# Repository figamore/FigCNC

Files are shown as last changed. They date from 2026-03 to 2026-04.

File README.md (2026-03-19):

# FigCNC

**FigCNC** is an open-source CNC controller board based on the ESP32 microcontroller, designed to run [FluidNC](https://github.com/bdring/FluidNC) firmware. It provides a compact and clean interface between the ESP32 and external stepper motor drivers, with optocoupler-isolated limit switch inputs, a tool-length probe input, onboard microSD storage for G-code files, and a pendant UART interface — all powered directly from the machine's 12–36 V supply rail.

FigCNC includes an RS485 interface (MAX3485 transceiver) for direct Modbus RTU control of Huanyang-compatible VFD spindles, making it suitable for machines that require closed-loop spindle speed management.

## Table of Contents

- [Features](#features)
- [Board Overview](#board-overview)
- [Electrical Specifications](#electrical-specifications)
- [PCB Layout](#pcb-layout)
- [Manufacturing](#manufacturing)
- [GPIO Pin Reference](#gpio-pin-reference)
- [Connectors](#connectors)
- [FluidNC Configuration](#fluidnc-configuration)
- [Provided Configuration Files](#provided-configuration-files)
- [Pendant](#pendant)
- [License](#license)

<br>

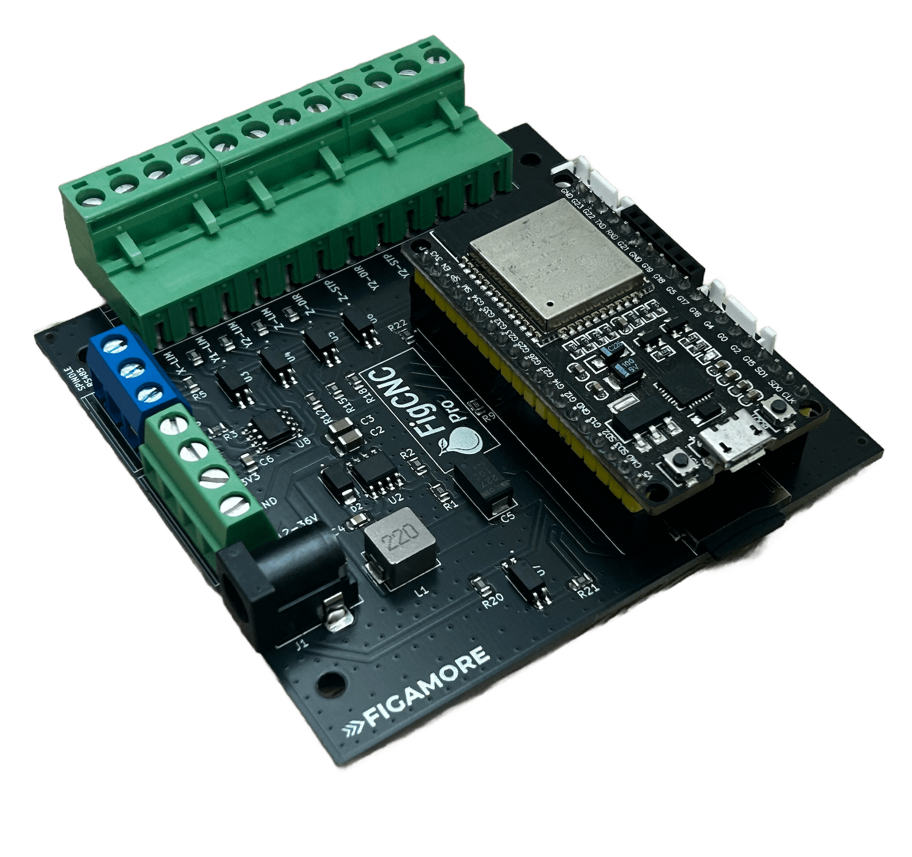
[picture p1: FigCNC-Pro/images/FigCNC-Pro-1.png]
FigCNC Pro — front isometric view


---

## Features

- **FluidNC native** — drop-in `config.yaml` configurations are provided for each axis and spindle combination. No firmware modifications required.
- **Wide input voltage** — 12 V to 36 V DC, regulated onboard to 5 V via the TPS5430DDA synchronous buck converter.
- **Four stepper channels** — X, Y1, Y2, and Z step/direction outputs on a single 12-pin Phoenix-style screw terminal. The second Y channel enables dual-motor gantry operation with independent homing.
- **Isolated limit switch inputs** — all four limit switch inputs and the probe input pass through LTV-817 optocouplers, keeping high-voltage switch wiring isolated from the ESP32.
- **Tool-length probe** — dedicated probe input (active-low) with optocoupler isolation.
- **MicroSD card** — SPI-connected microSD socket for storing G-code files. Accessible via the FluidNC web interface or over the serial connection.
- **Pendant interface** — UART2 exposed on a JST-XH connector for connecting a wired or wireless pendant.
- **UART / FTDI header** — a 4-pin header (RX, TX, GND, 5 V) provides direct serial access for firmware flashing and debug.
- **RS485 VFD spindle control** — a MAX3485 half-duplex RS485 transceiver and a dedicated 3-pin screw terminal for direct Modbus RTU control of Huanyang-compatible VFDs, eliminating the need for a PWM-to-analog converter.
- **Compact form factor** — four M3 mounting holes, compatible with standard DIN rail brackets and CNC controller enclosures.

---

## Board Overview

### Top view — connector layout

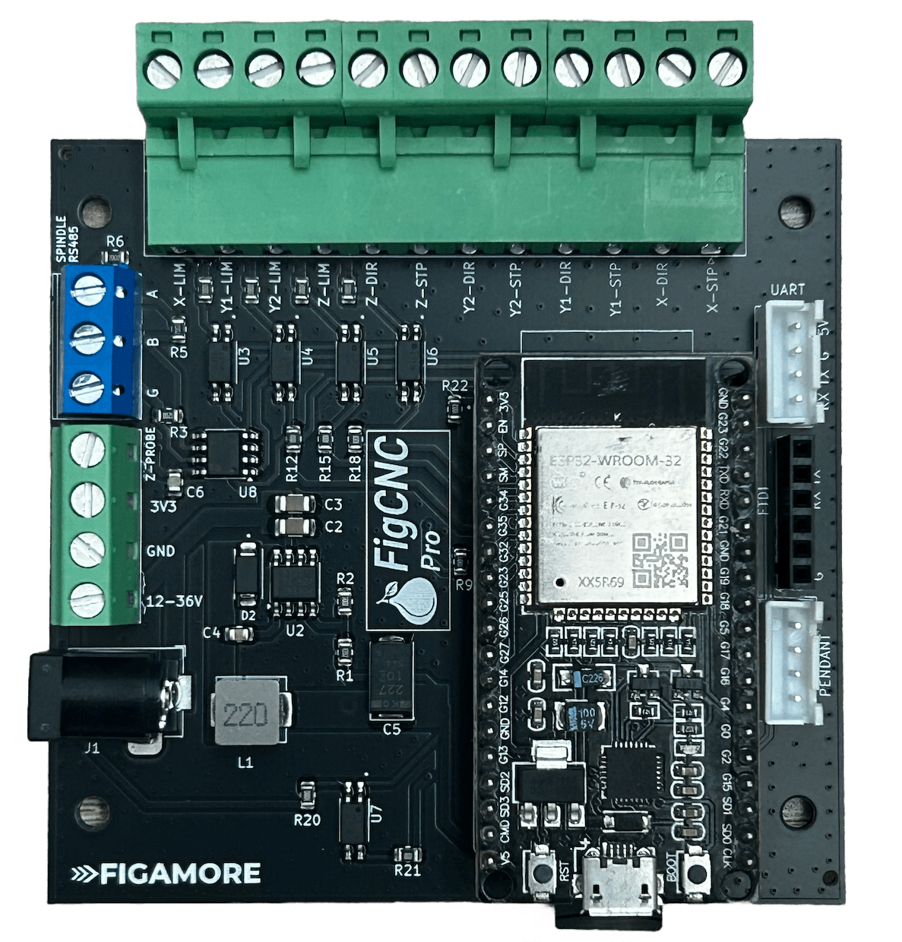
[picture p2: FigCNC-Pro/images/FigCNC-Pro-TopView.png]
FigCNC Pro — top view with connector labels


### Rear view

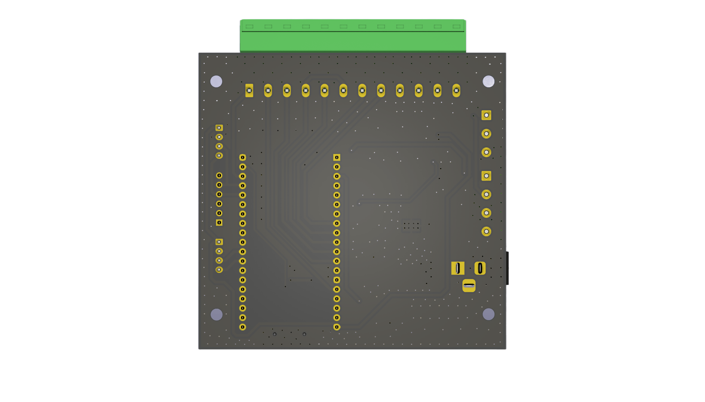
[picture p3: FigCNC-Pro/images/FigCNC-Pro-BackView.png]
FigCNC Pro — rear view


---

## Electrical Specifications

| Parameter | Value |
|---|---|
| Input voltage | 12–36 V DC |
| Input connector | 2.1 mm barrel jack |
| Onboard regulated output | 5 V (TPS5430DDA, up to 3 A) |
| Microcontroller | Espressif ESP32-DEVKITC-32E |
| Stepper interface | Step/Direction (StepStick-compatible signal levels) |
| Step pulse width | 10 µs (configurable in FluidNC) |
| Direction setup delay | 6 µs |
| Motor idle timeout | 250 ms |
| Limit / probe isolation | LTV-817 optocoupler (×5) |
| RS485 transceiver | Maxim MAX3485, 120 Ω termination fitted |
| MicroSD interface | SPI Mode @ 8Mhz |

---

## PCB Layout

| Front copper | Back copper |
|---|---|
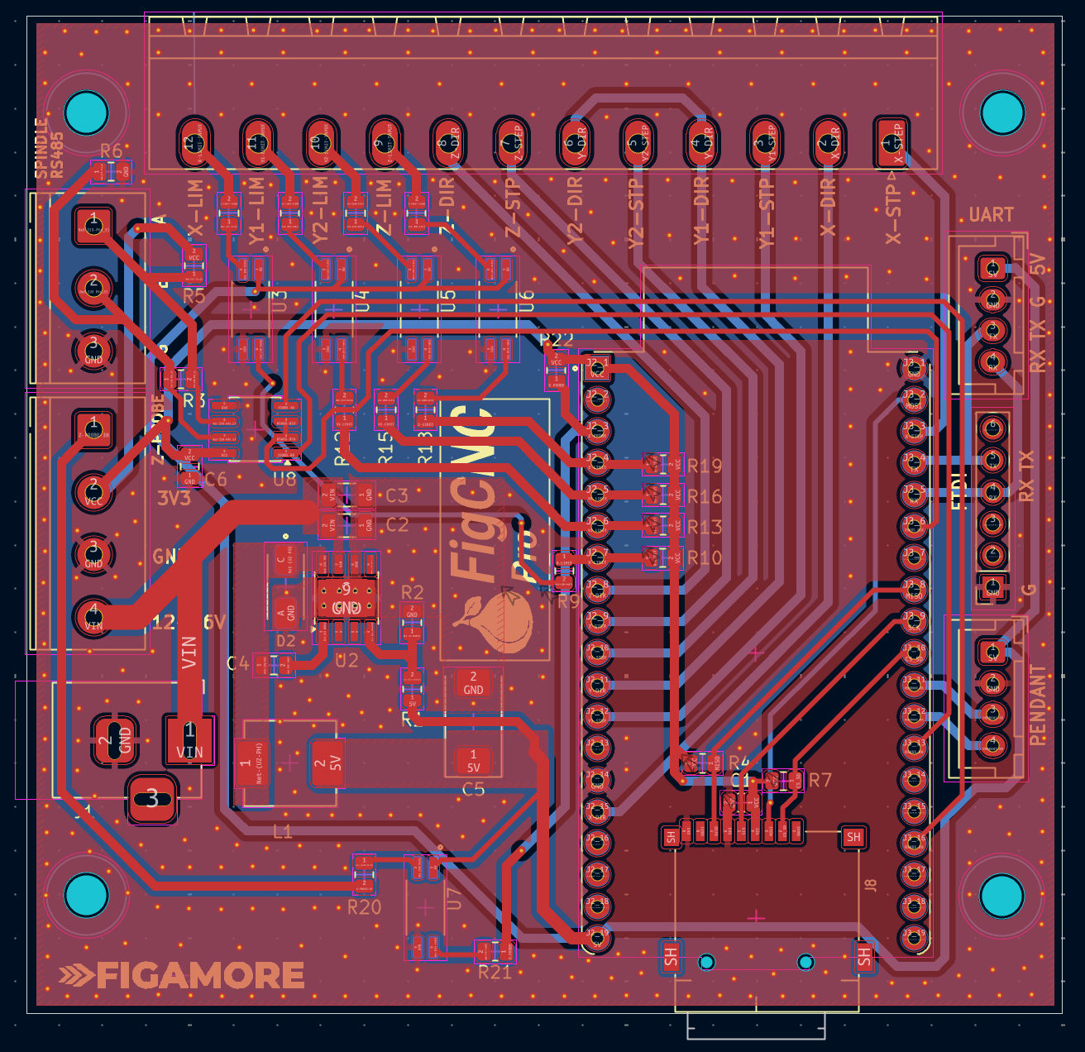
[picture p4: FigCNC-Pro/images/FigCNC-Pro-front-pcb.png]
Front PCB
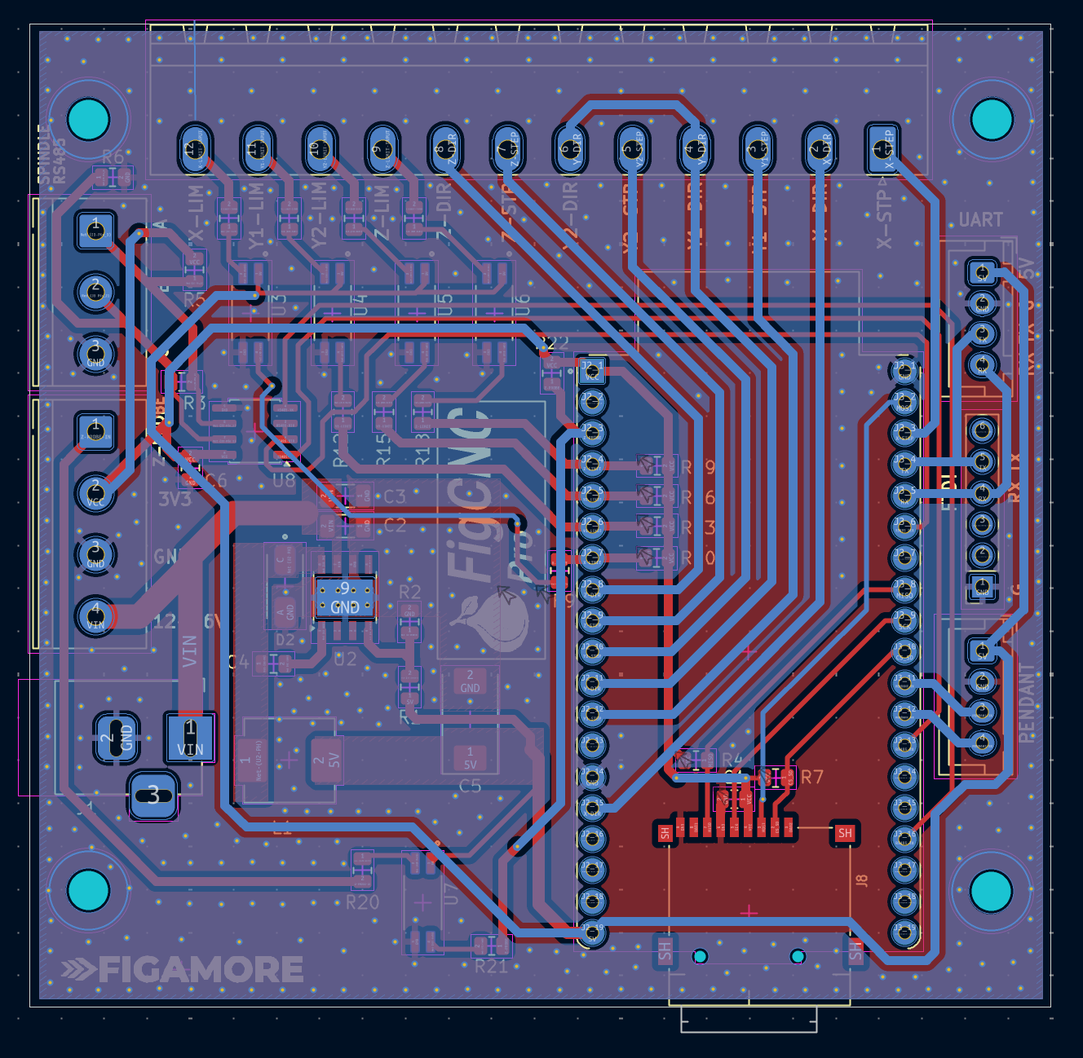
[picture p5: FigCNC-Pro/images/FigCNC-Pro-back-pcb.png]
Back PCB
|  |  |

FigCNC Pro Schematic

The full schematic is also available as a [PDF](FigCNC-Pro/schematic/FigCNC-Pro-Schematic.pdf).

---

## Manufacturing

All files required for PCB fabrication and assembly are included in each board's subdirectory.

| File type | Location |
|---|---|
| Gerber files (fabrication) | `FigCNC-Pro/gerbers/` |
| Drill files (.drl) | Included in gerbers directory |
| Bill of materials (CSV) | `FigCNC-Pro/FigCNC-Pro-BOM.csv` |
| Pick-and-place positions | `FigCNC-Pro/FigCNC-Pro-positions.csv` |
| Schematic (PDF / SVG) | `FigCNC-Pro/schematic/` |

The Gerber files have been validated for standard 2-layer PCB fabrication. The board can be ordered from any standard PCB manufacturer (e.g. JLCPCB, PCBWay, OSH Park) using the provided files without modification.

---

## GPIO Pin Reference

All GPIO assignments below correspond to the provided `config.yaml` files and the board's fixed routing. They should not be changed unless the PCB is modified.

| Signal | ESP32 GPIO |
|---|---|
| X — Step | 22 |
| X — Direction | 13 |
| X — Limit (positive) | 32 |
| Y1 — Step | 14 |
| Y1 — Direction | 27 |
| Y1 — Limit (positive) | 35 |
| Y2 — Step (dual-Y only) | 26 |
| Y2 — Limit (positive, dual-Y only) | 34 |
| Z — Step | 25 |
| Z — Direction | 33 |
| Z — Limit (positive) | 39 |
| Probe (active-low) | 36 |
| SPI MISO | 19 |
| SPI MOSI | 23 |
| SPI SCK | 18 |
| MicroSD CS | 5 |
| UART1 TX — VFD RS485 | 15 |
| UART1 RX — VFD RS485 | 4 |
| UART1 RTS — VFD RS485 | 21 |
| UART2 TX — Pendant | 17 |
| UART2 RX — Pendant | 16 |

---

## Connectors

### J4 — Stepper/limit-switches interface (12-pin Phoenix screw terminal, 5.08 mm pitch)

This is the primary stepper output terminal. Connect each signal to the corresponding input of your external stepper drivers (e.g. TB6600, DM542, or similar).

| Pin | Signal | Notes |
|---|---|---|
| 1 | X-LIM | X-axis limit switch (optocoupler input) |
| 2 | Y1-LIM | Y1 limit switch (optocoupler input) |
| 3 | Y2-LIM | Y2 limit switch (optocoupler input, dual-Y only) |
| 4 | Z-LIM | Z-axis limit switch (optocoupler input) |
| 5 | Z-DIR | Z direction output |
| 6 | Z-STP | Z step output |
| 7 | Y2-DIR | Y2 direction output (dual-Y only) |
| 8 | Y2-STP | Y2 step output (dual-Y only) |
| 9 | Y1-DIR | Y1 direction output |
| 10 | Y1-STP | Y1 step output |
| 11 | X-DIR | X direction output |
| 12 | X-STP | X step output |

### J3 — RS485 spindle (3-pin Phoenix screw terminal, 5.00 mm pitch)

Connect to the RS485 terminals of a Huanyang-compatible VFD. A 120 Ω termination resistor is fitted on the board.

| Pin | Signal |
|---|---|
| 1 | A (+) |
| 2 | B (−) |
| 3 | GND |

### J7 — Pendant (JST-XH 4-pin)

| Pin | Signal |
|---|---|
| 1 | 5 V |
| 2 | GND |
| 3 | RX (from pendant) |
| 4 | TX (to pendant) |

### J6 — UART / FTDI header (2.54 mm pitch, 4-pin)

| Pin | Signal |
|---|---|
| 1 | RX |
| 2 | TX |
| 3 | GND |
| 4 | 5 V |

### Probe input

The probe input is located on the left-side screw terminal block (J1). Connect the probe to the designated probe pin and GND. The input is active-low and optocoupler-isolated.

---

## FluidNC Configuration

FigCNC runs [FluidNC](https://github.com/bdring/FluidNC), an ESP32-based CNC firmware compatible with G-code senders such as [FluidDial](https://github.com/bdring/FluidDial), [CNCjs](https://cncjs.org), [UGS](https://winder.github.io/ugs_website/), and [Candle](https://github.com/Denvi/Candle).

Configuration is done via a single `config.yaml` file stored on the ESP32 (uploaded via the FluidNC web interface or over serial). Ready-to-use configuration files are provided for each supported machine topology.

### Default axis parameters

These values match the provided configurations and serve as a reference starting point. **You must adjust `steps_per_mm`, `max_rate_mm_per_min`, `acceleration_mm_per_sec2`, and `max_travel_mm` in the config file to match your specific machine geometry, lead screw pitch, microstepping settings, and motors before running the machine.**

| Axis | Steps/mm | Max rate (mm/min) | Acceleration (mm/s²) | Max travel (mm) |
|---|---|---|---|---|
| X | 320 | 2500 | 100 | 327 |
| Y | 400 | 3000 | 100 | 327 |
| Z | 320 | 1600 | 100 | 95 |

### VFD spindle parameters (with-VFD configs)

| Parameter | Value |
|---|---|
| Protocol | Huanyang Modbus RTU |
| Baud rate | 9600 |
| Modbus ID | 1 |
| Speed map | 0–25% → 0 RPM, 25–100% → 6000–24000 RPM |

---

## Provided Configuration Files

Pre-built `config.yaml` files are included for the following machine topologies. Upload the appropriate file to the ESP32 using the FluidNC web interface or over serial before running the machine.

| Configuration | Path |
|---|---|
| Single Y-axis, no VFD | `FigCNC-Pro/configs/single-y-axis-no-vfd/config.yaml` |
| Single Y-axis, with Huanyang VFD | `FigCNC-Pro/configs/single-y-axis-with-vfd/config.yaml` |
| Dual Y-axis, no VFD | `FigCNC-Pro/configs/double-y-axis-no-vfd/config.yaml` |
| Dual Y-axis, with Huanyang VFD | `FigCNC-Pro/configs/double-y-axis-with-vfd/config.yaml` |

---

## Pendant

FigCNC is designed to work with a 3D-printable pendant enclosure for the [FluidDial](https://github.com/bdring/FluidDial) CNC pendant, built around the Cheap Yellow Display (CYD / ESP32-2432S028R). The enclosure files, assembly instructions, and wiring reference are included in this repository.

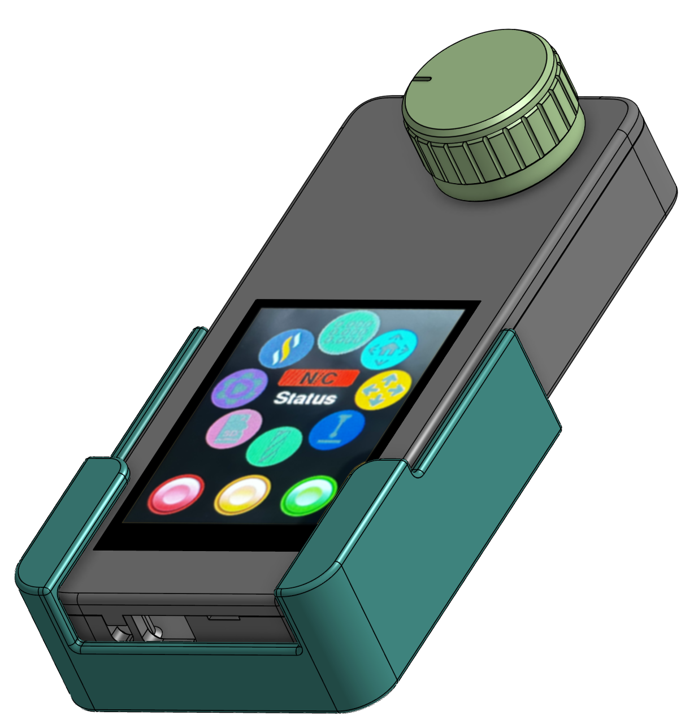
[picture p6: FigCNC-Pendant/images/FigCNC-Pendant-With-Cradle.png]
FigCNC Pendant with cradle


See the [FigCNC Pendant README](FigCNC-Pendant/README.md) for full details.

---

## License

This project is licensed under the **CERN Open Hardware Licence v2 - Permissive (CERN-OHL-P v2)**. You are free to use, modify, and manufacture the hardware for personal and commercial purposes, with or without releasing your modifications, provided attribution is maintained.

See [LICENSE](LICENSE) for full terms. This project is not affiliated with FluidNC or FluidDial — it is simply designed to run their firmware.

> [!CAUTION]
> This hardware is provided as-is. Use at your own risk. The developer accepts no responsibility for any damage to equipment, property, or injury arising from the use, assembly, or operation of this project.

---

*Designed by FIGAMORE.*

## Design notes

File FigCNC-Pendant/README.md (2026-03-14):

# FigCNC Pendant

A 3D-printable enclosure and cradle for a FluidNC CNC pendant (FluidDial), designed to fit the **Cheap Yellow Display (CYD / Guition JC2432W328C Capacitative)** and a standard rotary encoder module. This project is a custom case built around [FluidDial](https://github.com/bdring/FluidDial) — all pendant functionality is provided by the FluidDial firmware; this repository contains only the printable enclosure files.

FigCNC Pendant with cradle

The STL files are also available on Makerworld: [FigCNC FluidDial Pendant for FluidNC Controllers](https://makerworld.com/en/models/2523075-figcnc-fluiddial-pendant-for-fluidnc-controllers)

---

## Printed Parts

| File | Description |
|---|---|
| `FigCNC-Pendant-Case.stl` | Main enclosure body |
| `FigCNC-Pendant-Lid.stl` | Snap-fit rear lid |
| `FigCNC-Pendant-Knob.stl` | Knob for the rotary encoder |
| `FigCNC-Pendant-Cradle.stl` | Desktop cradle / holder |

---

## Bill of Materials

| Item | Quantity |
|---|---|
| CYD — ESP32-2432S028R (Cheap Yellow Display) | 1 |
| Rotary encoder module (HW-040 or equivalent) | 1 |
| M3 × 16 mm bolts | 2 |
| M3 nuts | 2 |
| M3 × 16 mm screws (CYD mounting) | 4 |
| 4-wire cable (to FigCNC pendant header) | 1 |

---

## Firmware

Flash the CYD with the FluidDial firmware before assembly using the web installer:

**https://installer.fluidnc.com**

Select the FluidDial target, connect the CYD over USB, and follow the on-screen instructions. No additional configuration is required beyond what FluidDial provides.

---

## Wiring

### Rotary encoder — CYD connections

Wire the encoder module to the CYD before fitting it into the case. Refer to the image below for connector locations.

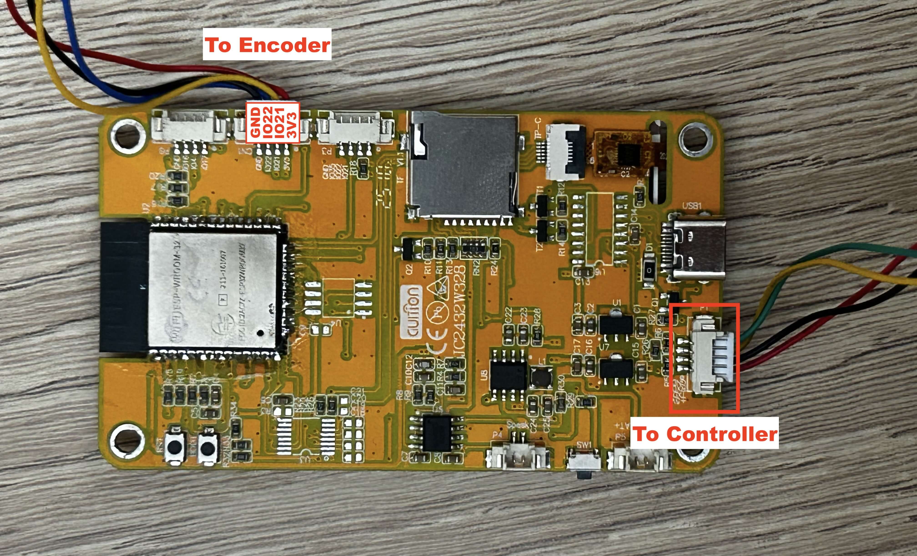
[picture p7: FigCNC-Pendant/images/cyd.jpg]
CYD wiring reference


| Encoder pin | CYD pin |
|---|---|
| CLK | IO22 |
| DT | IO21 |
| + | 3V3 |
| GND | GND |

### Pendant cable — FigCNC connections

Connect the pendant cable to the **J5 pendant header** on the FigCNC board.

| CYD pin | FigCNC J5 pin |
|---|---|
| TX | RX (from pendant) |
| RX | TX (to pendant) |
| GND | GND |
| 5V | 5V |

> Note: TX and RX are crossed — the CYD's transmit connects to the FigCNC receive, and vice versa.

The pendant UART on FigCNC operates at 1,000,000 baud (configured in `config.yaml`). This matches the FluidDial default and requires no changes on either side.

---

## Assembly

### Step 1 — Pierce the encoder screw holes

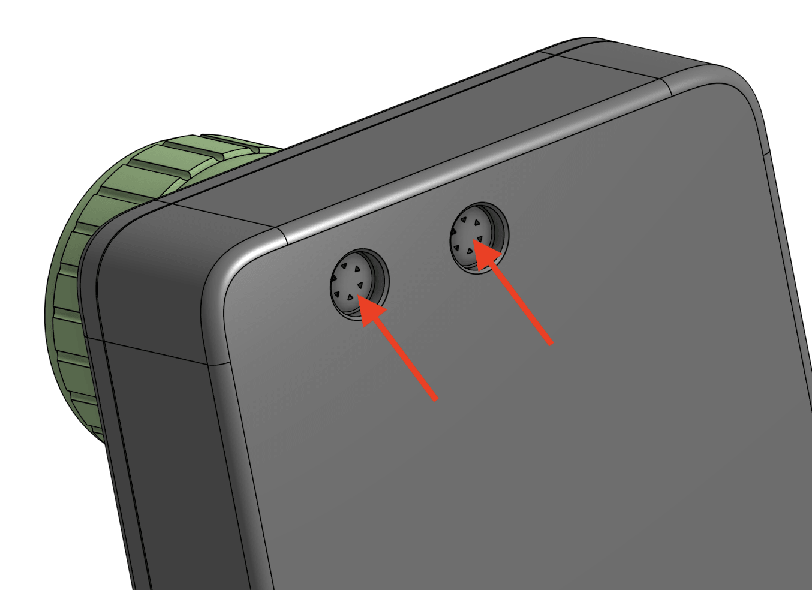
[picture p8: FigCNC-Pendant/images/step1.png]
Step 1


The two screw holes for the rotary encoder are covered by a thin layer of plastic left by the print. Use a small screwdriver or awl to pierce through the two points indicated by the red arrows, clearing the path for the M3 bolts.

### Step 2 — Insert the M3 bolts

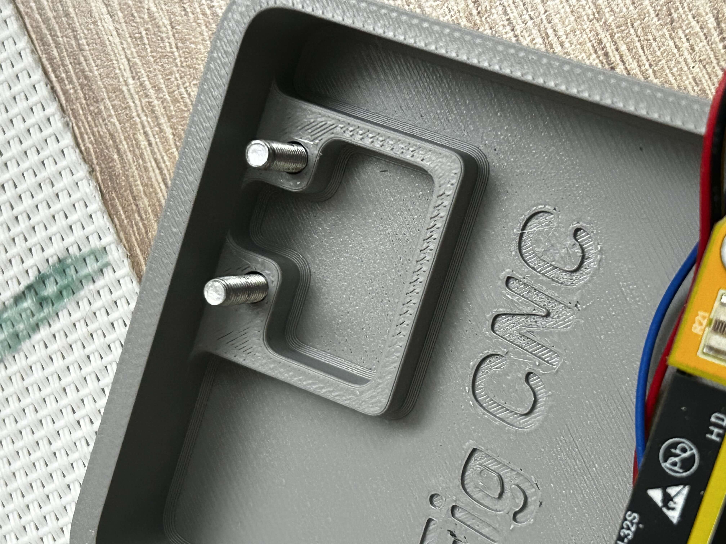
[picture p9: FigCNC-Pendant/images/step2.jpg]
Step 2


Drop two M3 × 16 mm bolts down through the cleared holes from the outside of the case. The bolt heads will sit flush against the top surface.

### Step 3 — Mount the rotary encoder

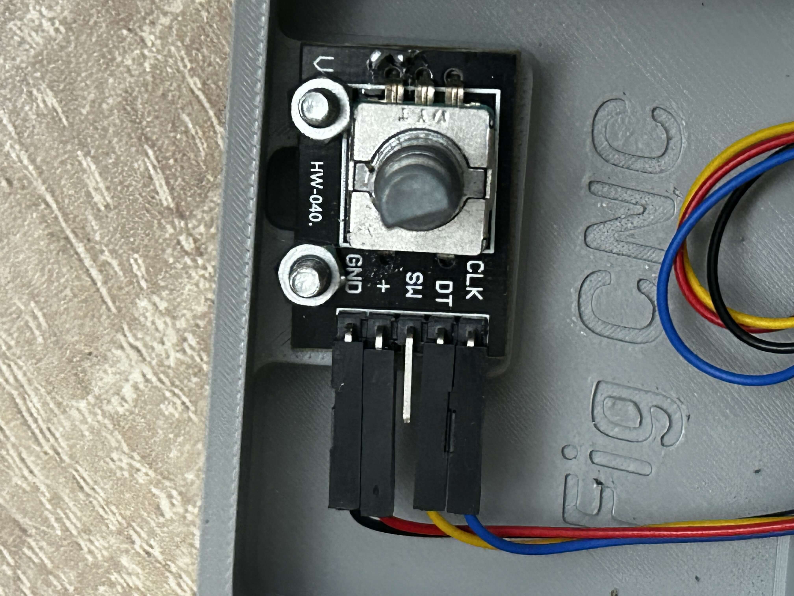
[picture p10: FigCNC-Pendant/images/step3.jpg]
Step 3


Connect your wiring to the rotary encoder module (CLK, DT, SW, +, GND), then seat the encoder onto the bolts and fasten it from inside with M3 nuts. The encoder module should sit flat against the mounting platform.

### Step 4 — Install the CYD

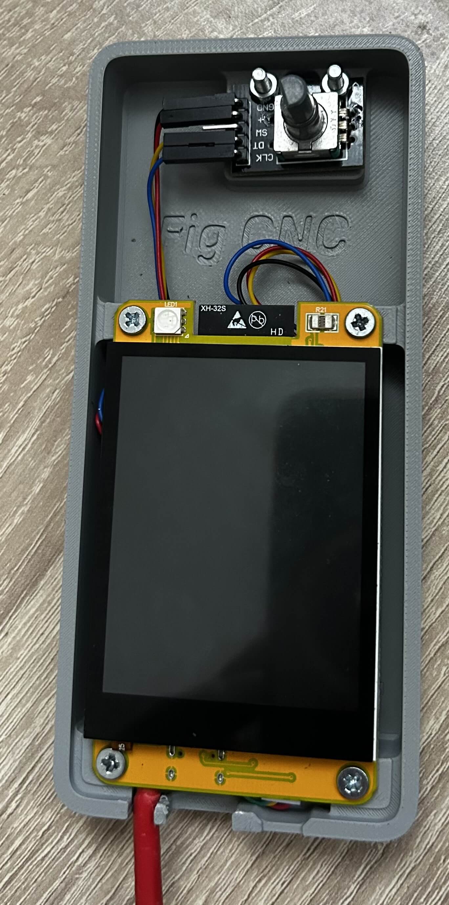
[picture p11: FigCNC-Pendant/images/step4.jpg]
Step 4


Attach the data cable to the CYD's connector. Route the cable beneath the CYD, then lower the CYD into the case and fasten it using four M3 screws into the corner standoffs.

### Step 5 — Attach the lid

The lid snaps onto the back of the case. No tools or fasteners required — press evenly around the perimeter until it clicks into place.

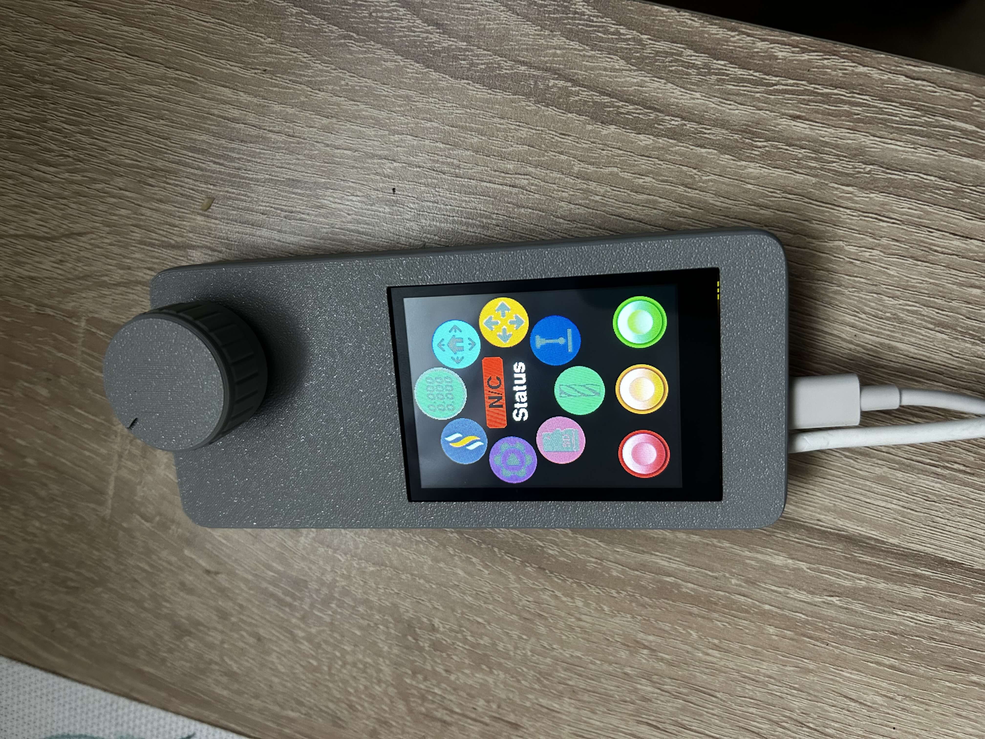
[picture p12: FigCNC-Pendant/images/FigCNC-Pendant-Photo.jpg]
Finished pendant


---

*Part of the [FigCNC](../README.md) open-source CNC controller project by FIGAMORE.*

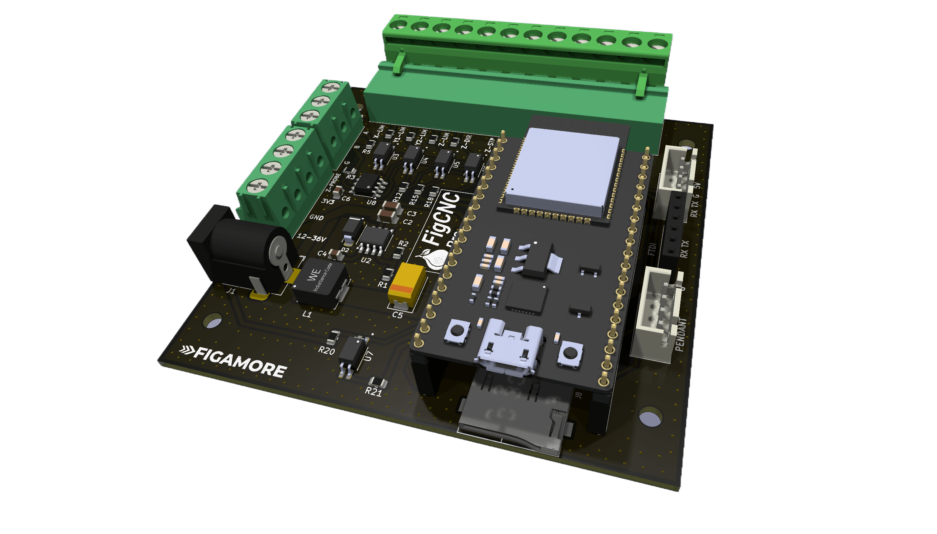
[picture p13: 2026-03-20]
FigCNC-Pro/images/FigCNC-Pro-2.png

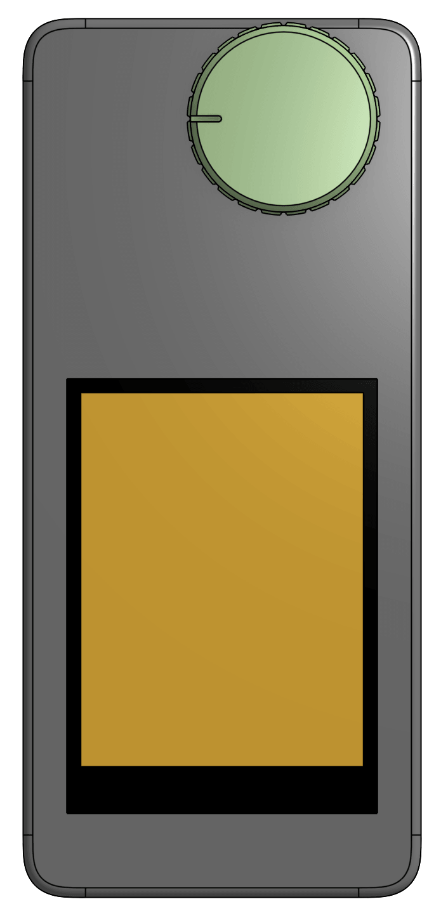
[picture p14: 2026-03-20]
FigCNC-Pendant/images/FigCNC-Pendant-Top.png

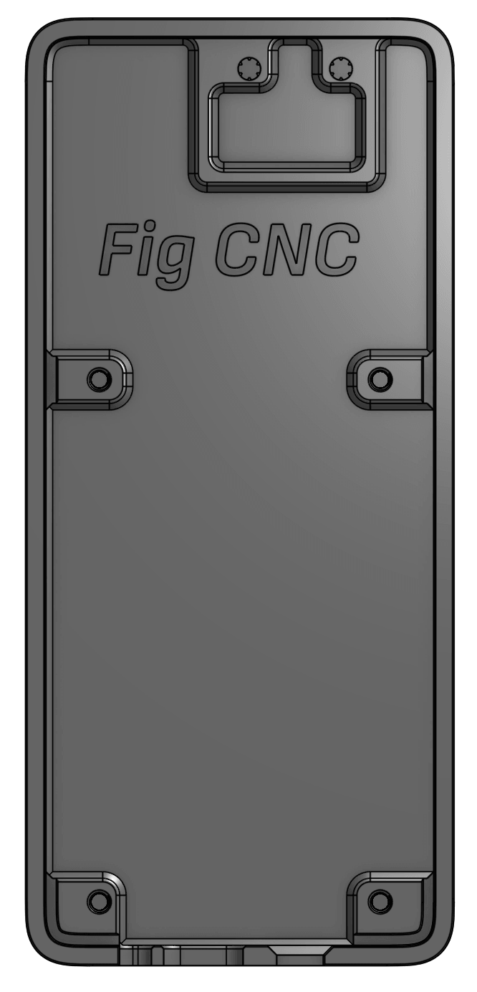
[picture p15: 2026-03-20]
FigCNC-Pendant/images/FigCNC-Pendant-Case.png

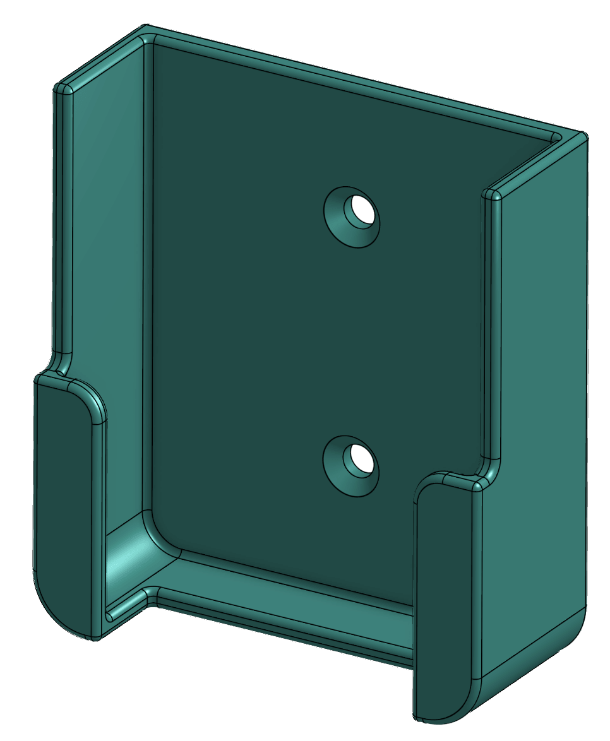
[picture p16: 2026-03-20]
FigCNC-Pendant/images/FigCNC-Pendant-Cradle.png

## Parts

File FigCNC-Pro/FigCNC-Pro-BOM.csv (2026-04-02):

Designator | Footprint | Quantity | Value | JLCPCB Part #
C1, C6 | 805 | 2 | 100nF | C49678
C2, C3 | 1206 | 2 | 4.7 µF | C29823
C4 | 805 | 1 | 10 nF | C1710
C5 | CP_EIA-7343-31_Kemet-D | 1 | 220 uF | C212691
D2 | DIOM5226X240N | 1 | SS34 | C8678
J1 | BarrelJack_Horizontal | 1 | Barrel_Jack_MountingPin
J2 | TerminalBlock_Phoenix_PT-1,5-4-5.0-H_1x04_P5.00mm_Horizontal | 1 | Screw_Terminal_01x05 | C5443561
J3 | TerminalBlock_Phoenix_PT-1,5-3-5.0-H_1x03_P5.00mm_Horizontal | 1 | Screw_Terminal_01x03 | C8270
J4 | PhoenixContact_MSTBA_2,5_12-G-5,08_1x12_P5.08mm_Horizontal | 1 | Screw_Terminal_01x12 | C26543
J5, J7 | JST_XH_B4B-XH-A_1x04_P2.50mm_Vertical | 2 | Conn_01x04_Pin | C161871
J6 | PinSocket_1x06_P2.54mm_Vertical | 1 | Conn_01x06_Pin | C5224026
J8 | J_SD_Card-micro_socket_A | 1 | 112A-TAAR-R03 | C91145
L1 | L_TechFuse_SL0630 | 1 | 22 µH | C22463831
R1, R10, R13, R16, R19, R22, R4, R7 | 805 | 8 | 10 K | C17414
R11, R14, R17, R20, R8 | 805 | 5 | 300 | C17617
R12, R15, R18, R21, R9 | 805 | 5 | 1 K | C17513
R2 | 805 | 1 | 3 K | C17661
R3 | 805 | 1 | 120 | C17437
R5, R6 | 805 | 2 | 20K | C4328
U2 | TI_SO-PowerPAD-8_ThermalVias | 1 | TPS5430DDA | C9864
U3, U4, U5, U6, U7 | SOIC127P700X210-4N | 5 | LTV-217 | C17407902
U8 | SOIC-8_3.9x4.9mm_P1.27mm | 1 | MAX3485 | C22447116

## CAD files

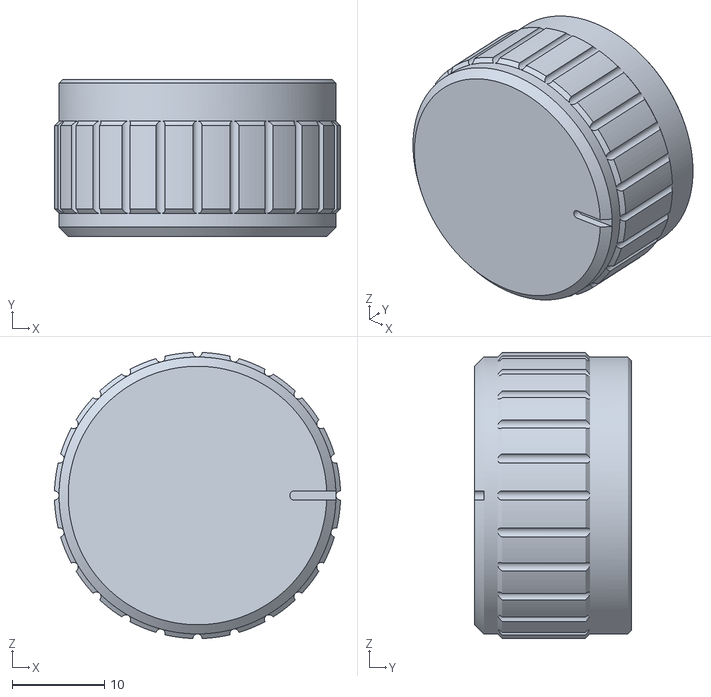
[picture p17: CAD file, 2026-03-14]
FigCNC-Pendant/FigCNC-Pendant-Knob.stl
31.0 x 17.0 x 31.0

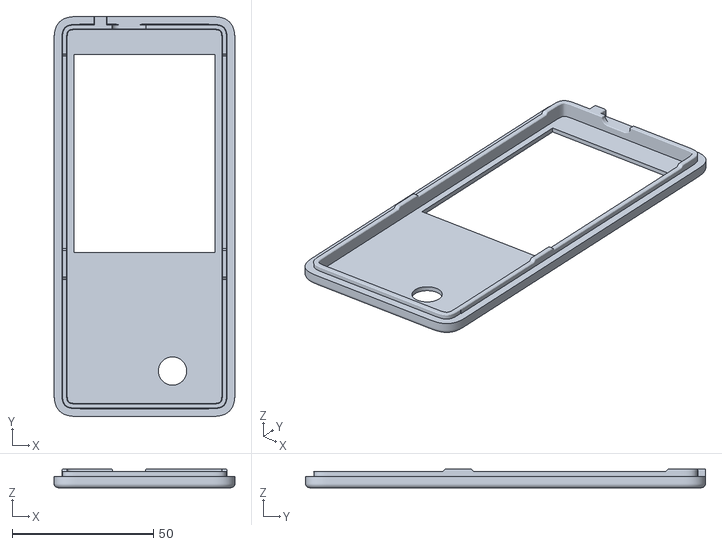
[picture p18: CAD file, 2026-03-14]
FigCNC-Pendant/FigCNC-Pendant-Lid.stl
64.0 x 141.5 x 6.55

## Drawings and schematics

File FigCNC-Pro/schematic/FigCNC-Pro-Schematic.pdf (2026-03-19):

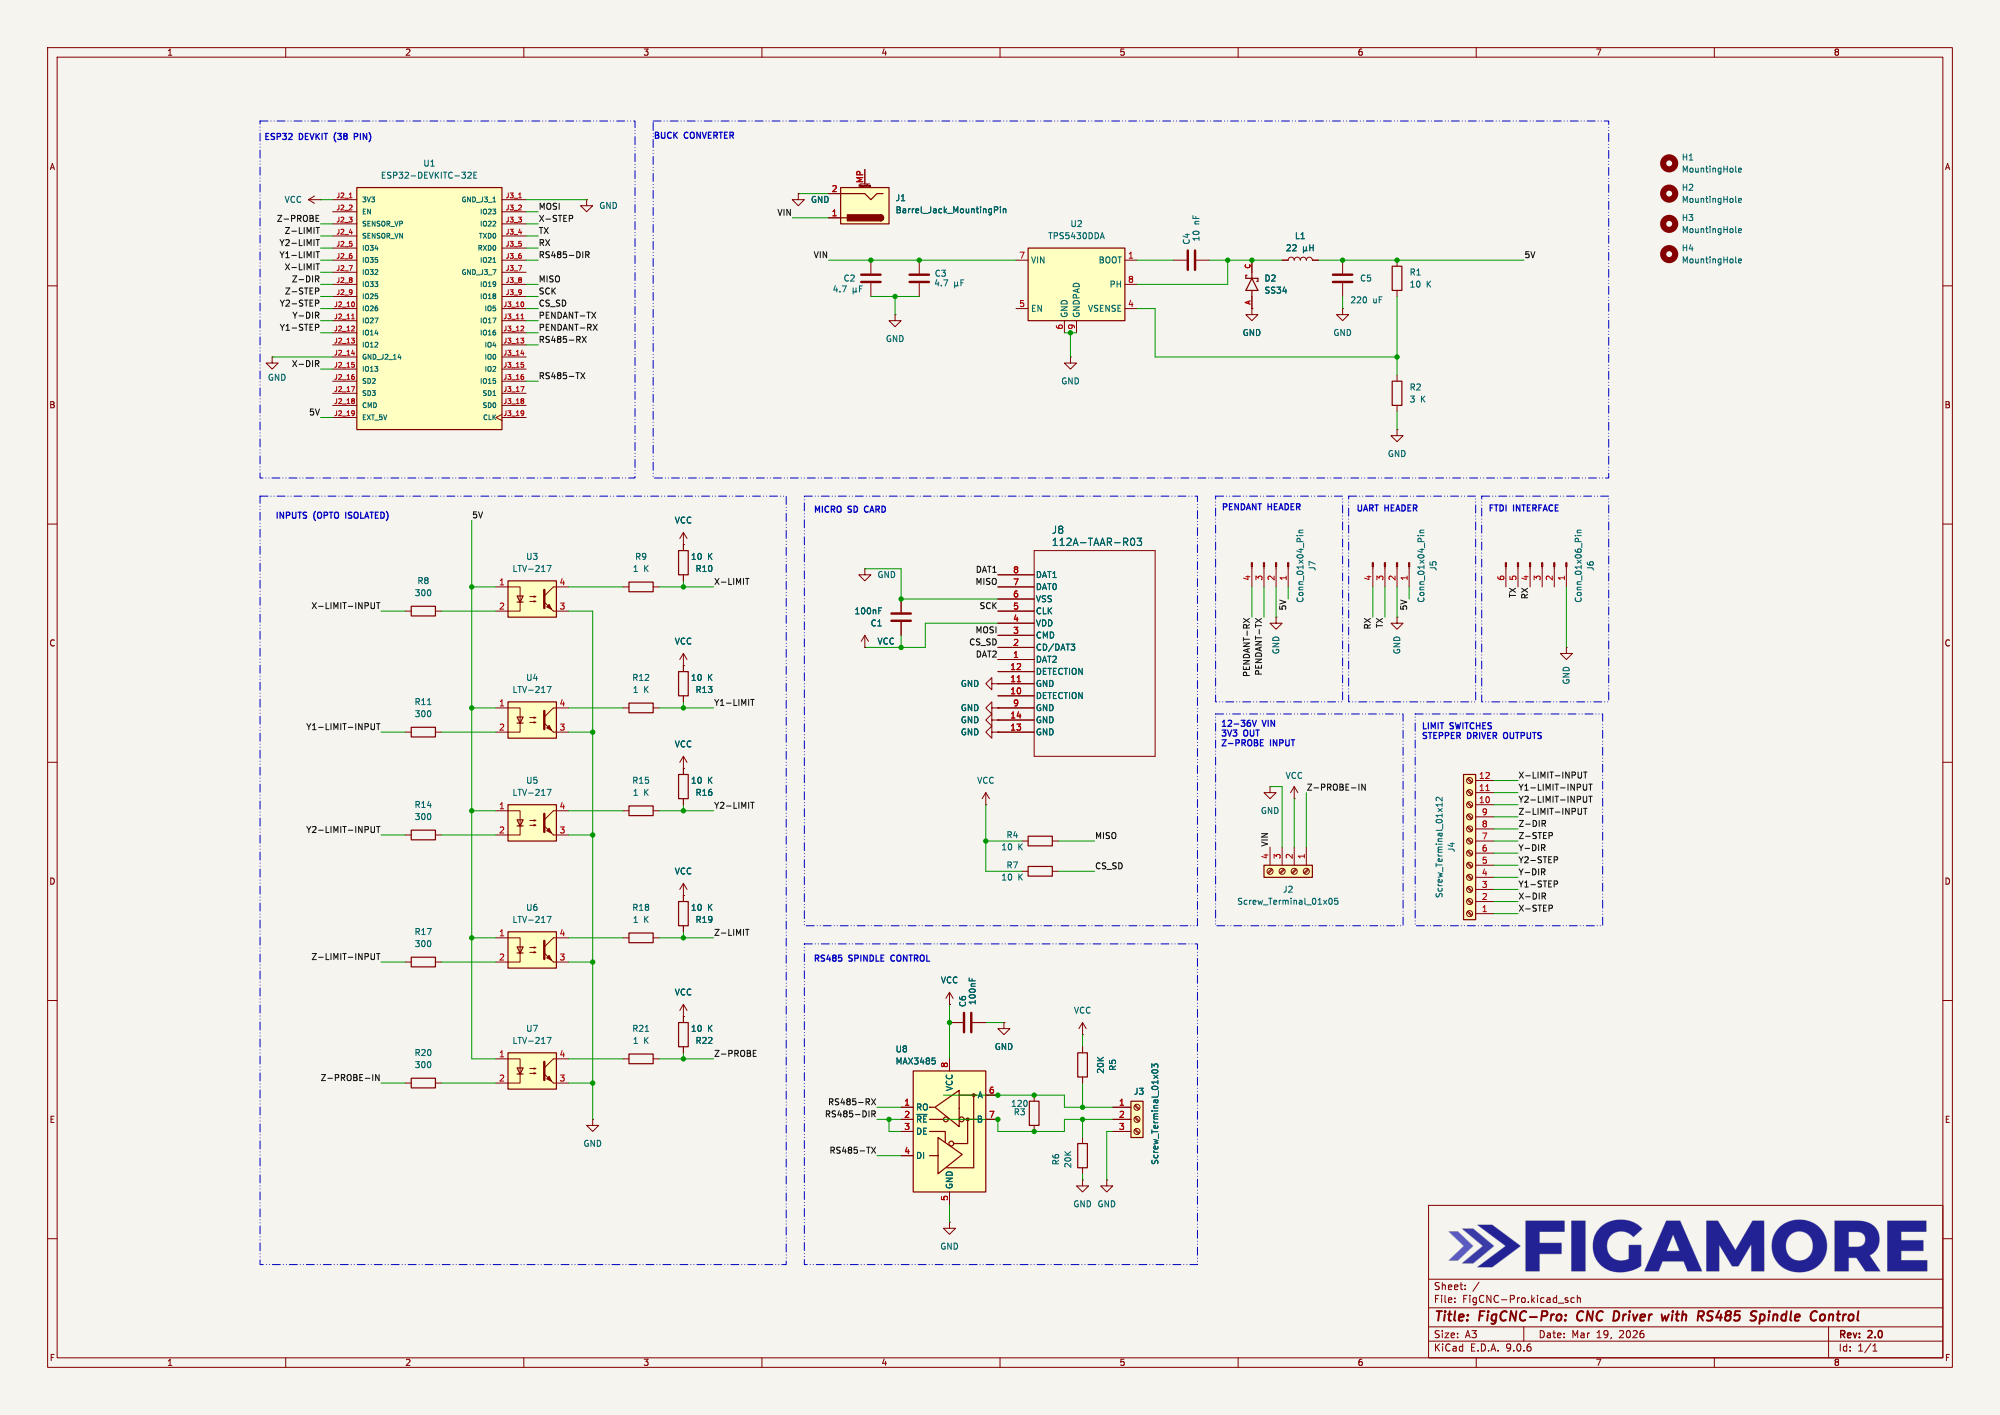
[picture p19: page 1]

INPUTS (OPTO ISOLATED) ESP32 DEVKIT (38 PIN)

STEPPER DRIVER OUTPUTS MICRO SD CARD

112A-TAAR-R03 GND GND GND

Z-LIMIT-INPUT Y2-LIMIT-INPUT

Z-LIMIT-INPUT Y1-LIMIT-INPUT Y2-LIMIT-INPUT

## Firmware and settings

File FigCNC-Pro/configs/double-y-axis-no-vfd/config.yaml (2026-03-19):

board: FigCNC
name: FigCNC Standard DOUBLE Y-AXIS
stepping:
  engine: RMT
  idle_ms: 250
  pulse_us: 10
  dir_delay_us: 6
  disable_delay_us: 0

axes:
  shared_stepper_disable_pin: NO_PIN
  x:
    steps_per_mm: 320.000         
    max_rate_mm_per_min: 2500.000  
    acceleration_mm_per_sec2: 100.000  
    max_travel_mm: 327
    soft_limits: true       
    homing:
      cycle: 1          
      positive_direction: true
      mpos_mm: 1.000    
      feed_mm_per_min: 300.000   
      seek_mm_per_min: 600.000   
      settle_ms: 500           
      seek_scaler: 1.100 
      feed_scaler: 1.100 

    motor0:
      limit_neg_pin: NO_PIN   
      limit_pos_pin: gpio.32
      limit_all_pin: NO_PIN
      hard_limits: false
      pulloff_mm: 1.000 
      stepstick:
        ms3_pin: NO_PIN
        step_pin: gpio.22
        direction_pin: gpio.13
        disable_pin: NO_PIN

  y:
    steps_per_mm: 400.000
    max_rate_mm_per_min: 3000.000
    acceleration_mm_per_sec2: 100.000
    max_travel_mm: 327.000
    soft_limits: true
    homing:
      cycle: 1
      positive_direction: true
      mpos_mm: 0.000
      feed_mm_per_min: 300.000
      seek_mm_per_min: 600.000
      settle_ms: 500
      seek_scaler: 1.100
      feed_scaler: 1.100

    motor0:
      limit_neg_pin: NO_PIN
      limit_pos_pin: gpio.35
      limit_all_pin: NO_PIN
      hard_limits: false
      pulloff_mm: 1
      stepstick:
        ms3_pin: NO_PIN
        step_pin: gpio.14
        direction_pin: gpio.27
        disable_pin: NO_PIN

    motor1:
      limit_neg_pin: NO_PIN
      limit_pos_pin: gpio.34
      limit_all_pin: NO_PIN
      hard_limits: false
      pulloff_mm: 1
      stepstick:
        ms3_pin: NO_PIN
        step_pin: gpio.26
        direction_pin: NO_PIN
        disable_pin: NO_PIN

  z:
    steps_per_mm: 320.000
    max_rate_mm_per_min: 1600.000
    acceleration_mm_per_sec2: 100.000
    max_travel_mm: 95.000
    soft_limits: true
    homing:
      cycle: 1
      positive_direction: true
      mpos_mm: 0.000
      feed_mm_per_min: 300.000
      seek_mm_per_min: 600.000
      settle_ms: 500
      seek_scaler: 1.100
      feed_scaler: 1.100

    motor0:
      limit_neg_pin: NO_PIN
      limit_pos_pin: gpio.39
      limit_all_pin: NO_PIN
      hard_limits: false
      pulloff_mm: 1.000
      stepstick:
        ms3_pin: NO_PIN
        step_pin: gpio.25
        direction_pin: gpio.33
        disable_pin: NO_PIN
        

control:
  safety_door_pin: NO_PIN
  reset_pin: NO_PIN
  feed_hold_pin: NO_PIN
  cycle_start_pin: NO_PIN

spi:
  miso_pin: gpio.19
  mosi_pin: gpio.23
  sck_pin: gpio.18


sdcard:
  cs_pin: gpio.5
  card_detect_pin: NO_PIN
  frequency_hz: 8000000

probe:
  pin: gpio.36:low
  check_mode_start: false

uart1:
  txd_pin: gpio.1
  rxd_pin: gpio.3
  rts_pin: NO_PIN
  cts_pin: NO_PIN
  baud: 1000000
  mode: 8N1

uart_channel1:
  uart_num: 1
  report_interval_ms: 75

# Pendant
uart2:
  txd_pin: gpio.17
  rxd_pin: gpio.16
  rts_pin: NO_PIN
  cts_pin: NO_PIN
  baud: 1000000
  mode: 8N1

uart_channel2:
  uart_num: 2
  report_interval_ms: 75

start:
  must_home: false

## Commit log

2026-03-19 Revision 2
    [FigCNC-B_Cu.gbr, FigCNC-B_Mask.gbr, FigCNC-B_Paste.gbr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]
2026-04-02 Update BOM and images
    [FigCNC-Pro-BOM.csv]
